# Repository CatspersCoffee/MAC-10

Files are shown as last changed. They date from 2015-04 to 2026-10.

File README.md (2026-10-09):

# MAC-10

An FPGA-based engine ignition controller (CDI), designed and built 2015–2017.

A Xilinx Spartan-6 runs a Z80 soft-core system (based on [socZ80](http://sowerbutts.com/socz80/)) with custom timer and capture peripherals. These measure engine position from a variable-reluctance pickup and fire a capacitor-discharge ignition stage on a stacked "top board".

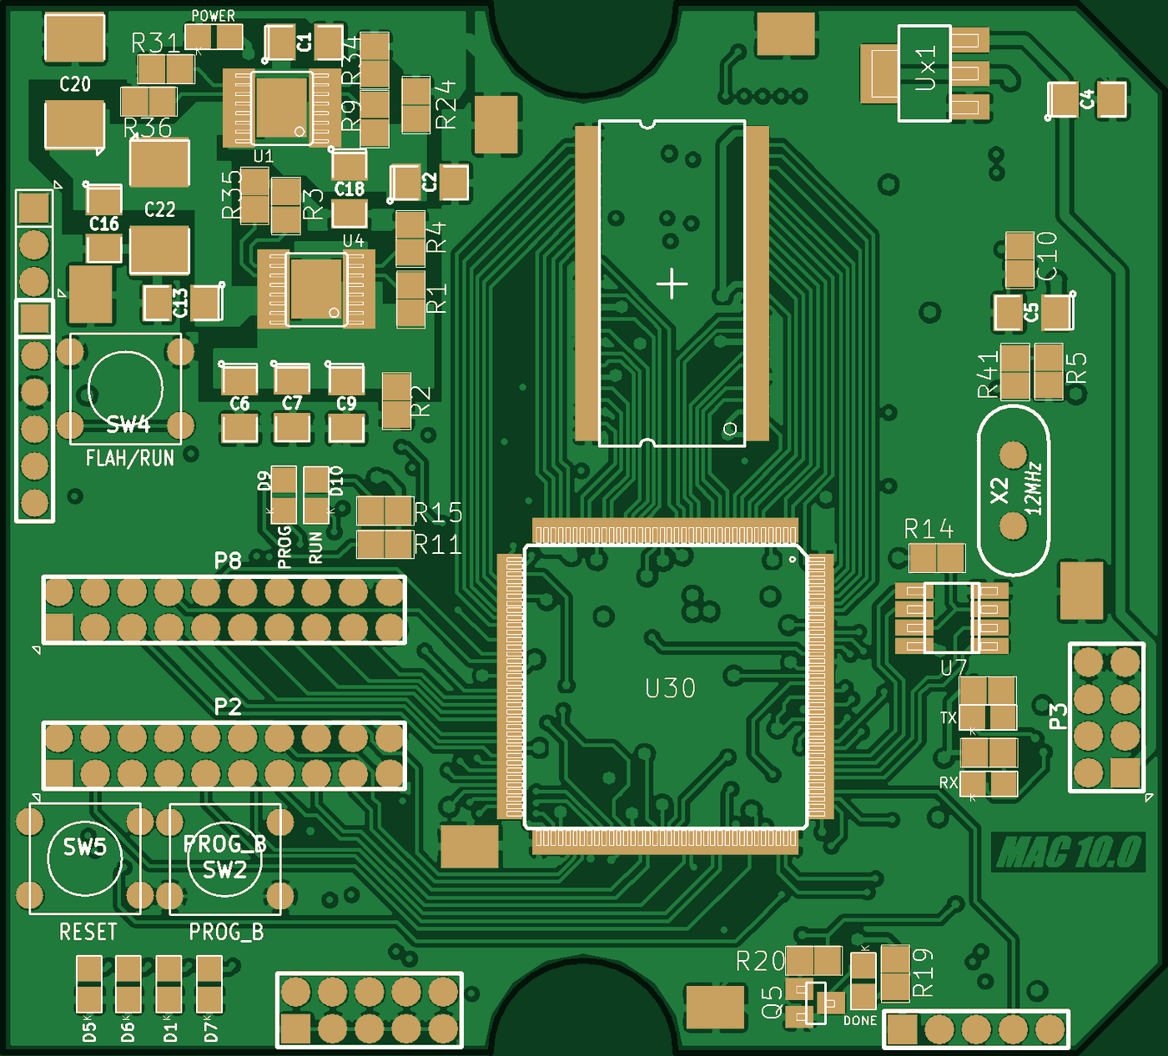
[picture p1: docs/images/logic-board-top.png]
MAC-10 logic board, top side (rendered from the fabrication gerbers)


> [!WARNING]
> The CDI board generates **several hundred volts DC** and drives an ignition coil. That can injure or kill. Do not build or power it unless you know how to work safely with high voltage.

## Boards

### Logic board: `hardware/logic-board/` (MAC10 REV 2.0)

| | |
|---|---|
| FPGA | Xilinx Spartan-6 **XC6SLX9-2TQG144** |
| Memory | Micron 256 Mb SDR SDRAM (16-bit), 2 × M25P80 SPI flash, XCF02S configuration PROM |
| Host link | FT232R USB-UART |
| Housekeeping | PIC18F2520 (programming / mode control), LT3081 regulators |
| Expansion | Two 20-pin headers (P8, P2) to the CDI board |

<p>
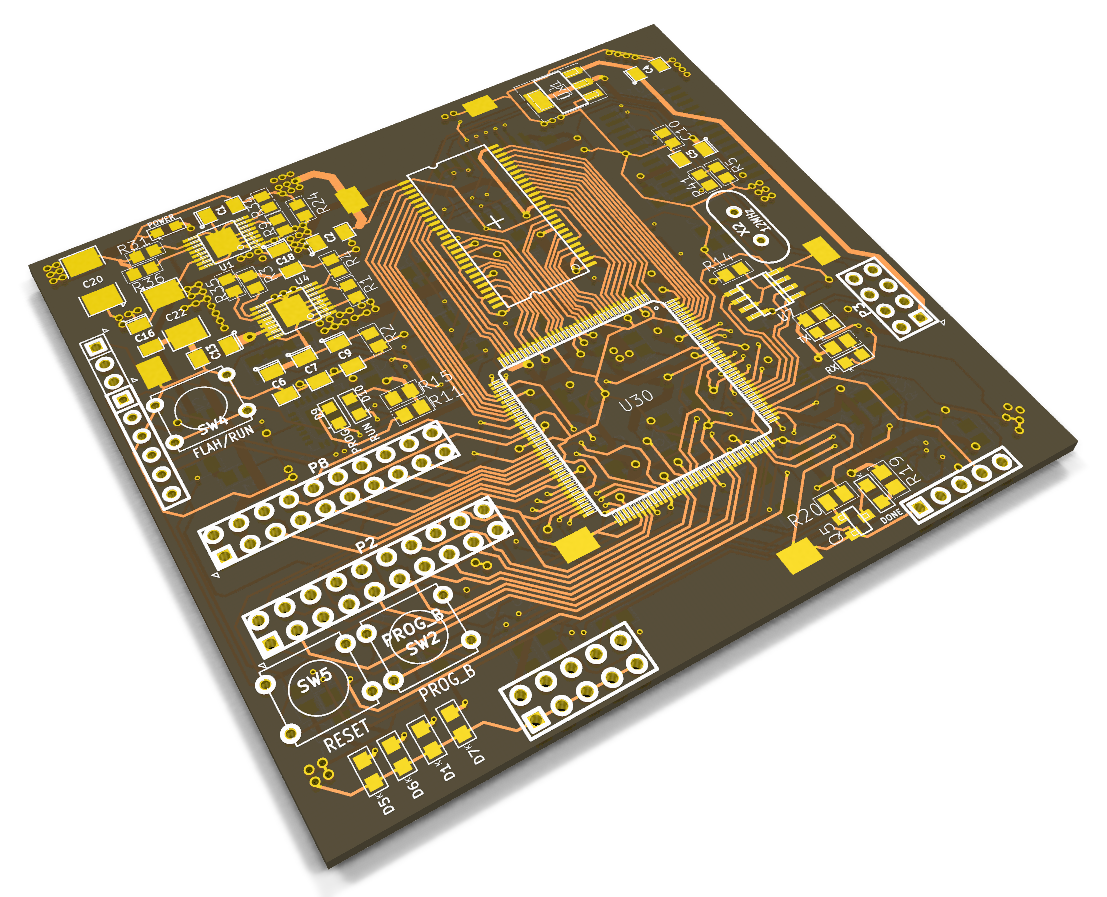
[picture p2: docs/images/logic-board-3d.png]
Logic board, 3D render

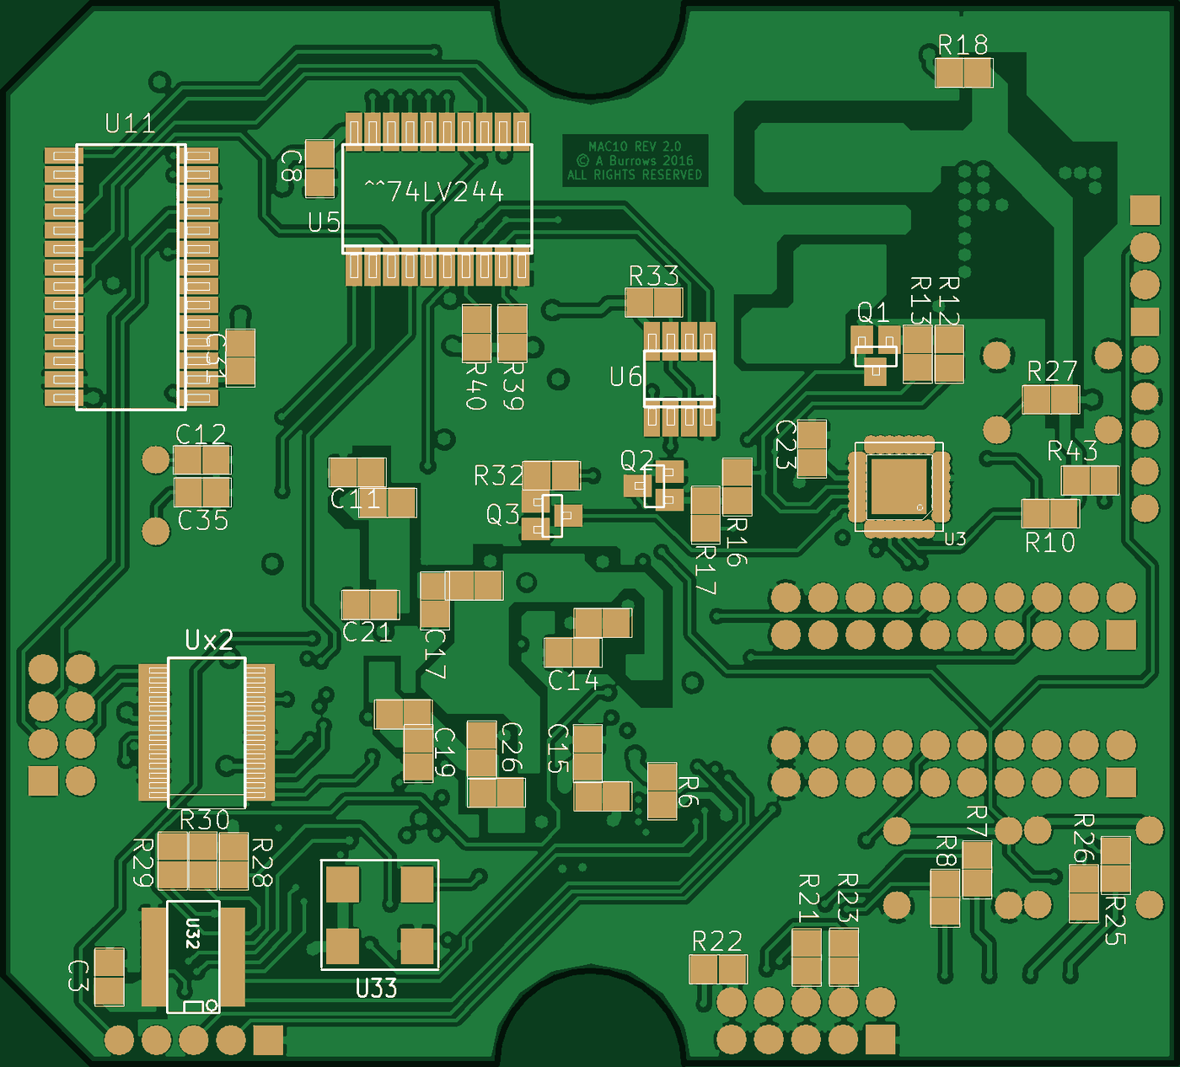
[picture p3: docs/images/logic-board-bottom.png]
Logic board, bottom side gerbers (mirrored)

</p>

### CDI board: `hardware/cdi-board/` (MAC10 TopB)

The top board stacks on the logic board through P8 (and P2 on the last revision). P8 pin 11 carries the ignition trigger from FPGA pin 59.

| | |
|---|---|
| HV supply | TL494 PWM, TC4427 driver and MOSFET push-pull into an ET029 transformer (rev 4). Earlier revisions used a MAX1771 boost converter and a BT151 SCR. |
| Crank sensing | MAX9926 variable-reluctance sensor interface |
| Temperature | MAX31855 K-type thermocouple converter |
| Inputs | MAX6816 switch debouncers, 74LVC245 level buffering |

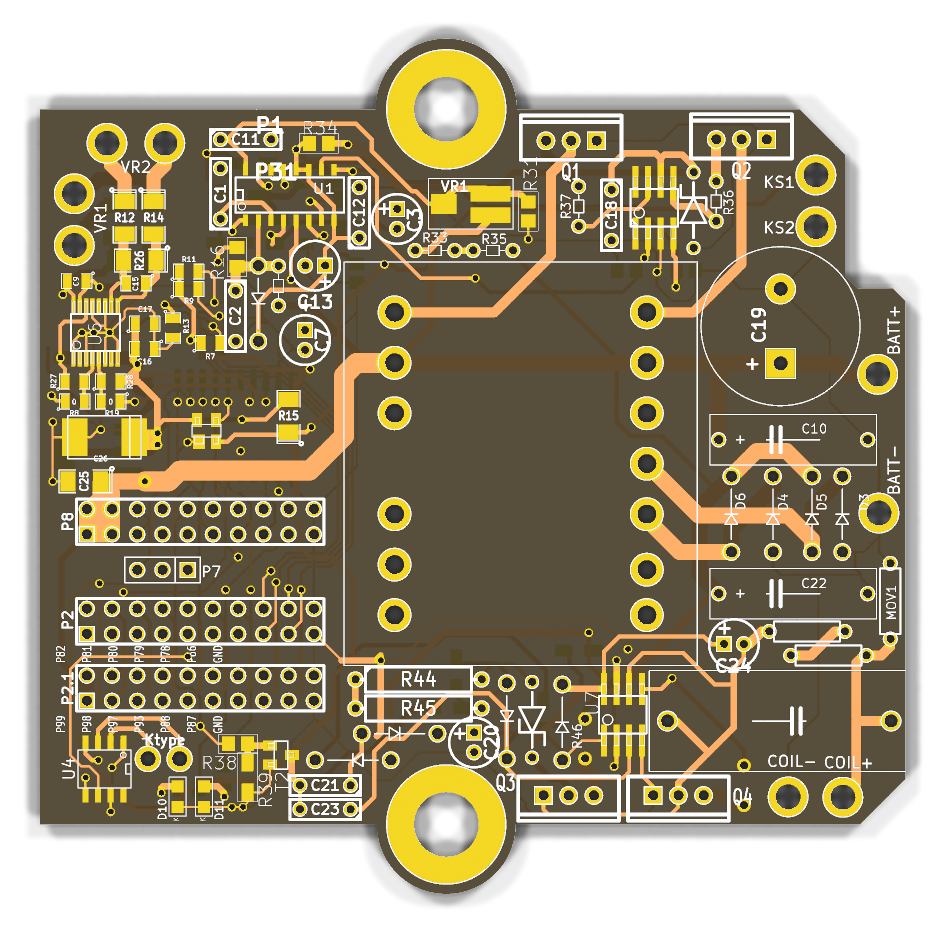
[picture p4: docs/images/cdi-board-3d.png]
CDI board, 3D render


### Gateware: `gateware/`

An ISE 14.7 project (`gateware/fpga/socz80.xise`, top level `top_level.vhd`, pinout `papilio_pro.ucf`) built on socZ80:

- **T80** Z80 CPU core, MMU, Mike Field's SDRAM controller, UARTs, SPI flash master (upstream socZ80)
- **Ignition timing peripherals** (MAC-10 additions):
  - `timerD2`: capture timer on I/O ports `0x50`–`0x57`
  - `timer3`: on `0x40`–`0x47`
  - `oneshot`: drives the CDI trigger output
- **`INTERRUPT_1`** interrupt controller, plus extra GPIO ports at `0x39`/`0x3A`
- **`hex_to_vhdl/`**: a small C tool that converts the Z80 monitor's Intel HEX into `MonZ80.vhd`, the boot ROM image

The last built bitstream is `gateware/fpga/work/top_level.bit`. The SPI PROM images are in `gateware/programming_files/`.

## Opening the files

- **KiCad:** the design files are in the 2013 KiCad format (`eeschema (2013-07-07 BZR 4022)-stable`).
  - **Boards** (`.brd`) open directly in current KiCad (checked with 10.0).
  - **Schematics** (`.sch`) need KiCad's legacy import: open the project in the KiCad GUI and accept the *Remap Symbols* step. The symbols come from each project's `*-cache.lib`, which is committed. The original custom libraries are not needed.
  - Gerbers and drill files are in each board's `GERBERS/`/`gerbers/` folder.
- **Xilinx ISE 14.7:** open `gateware/fpga/socz80.xise`. Build outputs are not committed; rebuild to regenerate them.

## History

This repository was assembled in 2026 from the original project folders. Each commit is one dated backup snapshot from the time, replayed in order. Commit dates are the real file dates, and each commit body names the original backup folder.

- `hardware/cdi-board/` passes through several design generations: TopV1, then the MAC-10.0 Test Board, then TopB 2/2E/3 (MAX1771 boost + SCR), then TopB 4 (TL494 push-pull redesign). The silkscreen REV labels don't follow the folder numbering. Each commit message gives both.
- Build outputs, editor backups, compiled executables and third-party datasheets were left out of every snapshot.

## License

- **Gateware, Z80 software and tools** (`gateware/`): [GPL-3.0-or-later](LICENSES/GPL-3.0-or-later.txt). This is required by socZ80. Upstream files keep their own headers and licenses (T80 and SSRAM are BSD-style).
- **Hardware** (`hardware/`): [CERN-OHL-S-2.0](LICENSES/CERN-OHL-S-2.0.txt).
- **Docs and images** (`docs/`): CC-BY-4.0.

The board silkscreens read "© A Burrows 2016 ALL RIGHTS RESERVED". This repository leaves the artwork exactly as it was fabricated. The notice predates this open release, and the hardware is licensed under CERN-OHL-S-2.0 as stated above.

Copyright © 2013–2017 Antony Burrows.

## Credits

- [socZ80](http://sowerbutts.com/socz80/) by William R. Sowerbutts (GPLv3): the SoC, monitor, CP/M and MP/M ports and tools this design builds on
- T80 Z80 core by Daniel Wallner
- SDRAM controller by Mike Field

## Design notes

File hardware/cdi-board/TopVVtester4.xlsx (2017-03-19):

1nF | 1 | C7
1000pF | 2 | C9 C15
4.7nF | 1 | C23
0.1uF | 1 | C17
100nF | 3 | C1 C2 C11
100nF X2 | 2 | C10 C22
120nF | 1 | C21
0.47uF 275VAC | 2 | C4 C5
1uF MMC | 2 | C12 C18
10uF | 1 | C16
100uF 16V | 2 | C20 C24
4700uF 16V LOW ESR | 1 | C19
10 uF | 5 | C3 C6 C8 C13 C14
1N4004 | 1 | D1
UF4007 | 5 | D3 D4 D5 D6 D13
1N4148 | 3 | D7 D8 D9
LED3 | 1 | D10
LED2 | 1 | D11
16V 1W | 1 | D2
75V 1W | 1 | D12
VARISTOR | 1 | MOV1
CONN_1 | 12 | P1 P3 P4 P5 P6 P9 P20 P21 P28 P29 P30 P31
CONN_10X2 | 3 | P2 P2.1 P8
CONN_3 | 1 | P7
STP60NF06 | 2 | Q1 Q2
FDP10N60 | 2 | Q3 Q4
0 | 2 | R8 R19
10 | 3 | R34 R36 R37
22 | 2 | R46 R47
300 | 1 | R11
330 | 2 | R22 R23
500 | 1 | R13
1K | 1 | R15
4.53k | 1 | R7
4K7 | 2 | R1 R20
5k | 2 | R25 R26
8K2 | 1 | R29
10K | 6 | R16 R24 R30 R31 R32 R38
10k | 4 | R10 R12 R14 R21
10k | 2 | R27 R28
13K | 1 | R40
33K | 3 | R41 R44 R45
47K | 2 | R3 R4
56K | 1 | R39
100K | 1 | R9
180K | 2 | R42 R43
270K | 2 | R33 R35
1M | 3 | R2 R17 R18
1M 0.25W | 2 | R5 R6
TRANSF_ET029 | 1 | T1
^^NPN-SOT23 | 1 | T2
TL494 | 1 | U1
OMEGA_PCC-SMP_K-TYPE | 1 | U2
TC4427 | 1 | U3
MAX31855 | 1 | U4
LT3081 | 1 | U5
L6571 | 1 | U7
MAX9926/9927 | 1 | U6
HV SEL | 1 | U8
74LVC245 | 1 | U10
100K | 1 | VR1

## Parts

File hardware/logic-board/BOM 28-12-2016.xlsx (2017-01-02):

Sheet: Sheet1
Field Value | Digikey Part # | Description | QTY
D3 D6 D7 D8 D9 | 1N4004DICT-ND | 1N4004 | 5 |  | HAVE via China
D1 D2 D4 | 1N5408RLGOSCT-ND | 1N5408 | 3 |  | HAVE via China
SF35 | SF35-TPMSCT-ND | SF35-TP | 1
L1 | ASPI-1306T-101M-TCT-ND | ASPI-1306T-101M-T | 1
L1_1 | 445-3599-1-ND |  | 1 |  | alternative sheilded inductor
L1_2 | 445-3852-1-ND |  | 1 |  | alternative sheilded inductor
R11 | 311-300ARCT-ND | RES SMD 300 OHM 5% 1/8W 0805 | 5
R13 | 311-510ARCT-ND | RES SMD 510 OHM 5% 1/8W 0805 | 5
R4 | 1.00KXBK-ND | RES 1K OHM 1/4W 1% AXIAL | 5 |  | HAVE via China
R15 | RNCP0805FTD1K00CT-ND | RES SMD 1K OHM 1% 1/4W 0805 | 5 | SMD0805
R2 | CF14JT4K70CT-ND | RES 4.7K OHM 1/4W 5% CARBON FILM | 5
R25 R26 | 541-5.1KUADKR-ND | RES SMD 5.1K OHM 5% 1/2W 1206 | 4 | SMD1206
R18 R20 R27 R28 | RHM10.0KCCT-ND | RES SMD 10K OHM 1% 1/8W 0805 | 10 | SMD0805
R10 R12 R14 R21 | RNCP1206FTD10K0CT-ND | RES SMD 10K OHM 1% 1/2W 1206 | 10 | SMD1206
R9 | 311-100KCRCT-ND | RES SMD 100K OHM 1% 1/8W 0805 | 5 | SMD0805
R5 R6 | RNF14FTD1M00CT-ND | RES 1M OHM 1/4W 1% AXIAL | 10 |  | HAVE via China
R17 | PT1.5MXCT-ND | RES SMD 1.5M OHM 5% 1W 2512 | 2 | SMD2512
R1 | CF14JT330RCT-ND | RES 330 OHM 1/4W 5% CARBON FILM | 5
R3 | S51CACT-ND | RES 51 OHM 1/4W 1% AXIAL | 5 |  | HAVE via China
R16 | P50MCT-ND | RES SMD 0.05 OHM 1% 1W 2512 | 2 | SMD2512
T1 | IRF644PBF-ND | MOSFET N-CH 250V 14A TO-220AB | 3
TH1 | KC002N-ND | THERMISTOR NTC 500 OHM @ 25C | 2
U3 | MAX1771ESA+-ND | IC REG CTRLR BST PWM 8-SOIC | 2
U7 | MAX6816EUS+TCT-ND | IC DEBOUNCER SWITCH SGL SOT143-4 | 2
U6 | MAX9926UAEE+TCT-ND | IC SENSOR INTERFACE VARI 16-QSOP | 2
VR1 | 3214W-502ECT-ND | TRIMMER 5K OHM 0.25W SMD | 2
C13 | PCF1412CT-ND | CAP FILM 0.1UF 5% 250VDC 2420 | 3 | SMD2420
C1 C3 C10 C11 | 490-1726-1-ND | CAP CER 0.1UF 25V Y5V 0805 | 10 | SMD0805
C7 | 478-1762-1-ND | CAP TANT 10UF 25V 10% 2312 | 3 | SMD2312
C18 | 478-1746-1-ND | CAP TANT 100UF 20V 10% 2917 | 2 | SMD2917
C6 | 399-3684-1-ND | CAP TANT 10UF 10V 10% 1206 | 2 | SMD1206
C8 | 478-8234-1-ND | CAP TANT 1UF 16V 20% 1206 | 2 | SMD1206
C12 | 478-4973-1-ND | CAP TANT 10UF 35V 20% 2312 | 1 | SMD2312 | changed package | OR change to 2917 (7343 metric)
C14 | 478-1710-1-ND | CAP TANT 2.2UF 35V 10% 2312 | 1 | SMD2312 | changed package
C2 | 445-8351-ND | CAP CER 10UF 25V X7R RADIAL | 1
C9 C15 | 445-1337-1-ND | CAP CER 1000PF 100V X7R 0805 | 10 | SMD0805
C4 C5 | P14596-ND | CAP FILM 1UF 5% 250VDC RADIAL | 4 |  | Lead Spacing 0.591" (15.00mm)
U30 | 122-1748-ND | XC6SLX9-3TQG144I | 1
U32 | 122-1288-5-ND | XCF04SVOG20C | 1
U33 | CTX277LVCT-ND | OSC XO 32.000MHZ HCMOS TTL SMD | 2
Ux2 | 768-1007-1-ND | IC USB FS SERIAL UART 28-SSOP | 1
X2 | 631-1105-ND | 12MHz ±30ppm Crystal 18pF HC49/US | 1
U6 U7 | M25P20-VMN6TPBCT-ND | IC FLASH 2MBIT 75MHZ 8SO | 2
U6 U7 | 1265-1133-1-ND | IC FLASH 8MBIT 75MHZ 8SO | 2
R34 | 311-66.5KCRCT-ND | RES SMD 66.5K OHM 1% 1/8W 0805 | 5 | SMD0805
R4 | P24.3KCCT-ND | RES SMD 24.3K OHM 1% 1/8W 0805 | 5 | SMD0805
R10 R27 R39 R40 | RHM10.0KCCT-ND | RES SMD 10K OHM 1% 1/8W 0805 | 10 | SMD0805
R6 R28 R30 R43 | 311-4.70KCRCT-ND | RES SMD 4.7K OHM 1% 1/8W 0805 | 10 | SMD0805
R1 R9 | 311-4.53KCRCT-ND | RES SMD 4.53K OHM 1% 1/8W 0805 | 5 | SMD0805
R14 R33 R35 R36 | RNCP0805FTD1K00CT-ND | RES SMD 1K OHM 1% 1/4W 0805 | 10 | SMD0805
R3 R31 | 311-510ARCT-ND | RES SMD 510 OHM 5% 1/8W 0805 | 5 | SMD0805
R21 R22 R23 | 311-100CRCT-ND | RES SMD 100 OHM 1% 1/8W 0805 | 5 | SMD0805
C5 | 399-8273-1-ND | CAP TANT 0.22UF 35V 10% 1206 | 2 | SMD1206
C20 C22 | 478-4973-1-ND | CAP TANT 10UF 35V 20% 2312 | 1 | SMD2312
X1 | 631-1122-1-ND | OSCILLATOR XO 1.000MHZ HCMOS SMD | 1 | SMD
U72 | 296-12896-5-ND | 74HC27 | 5
U19 | 296-12892-5-ND | 74HC20 | 2
U5 U71 U81 | 296-1589-5-ND | 74HC32 | 8
U15 | 296-2138-5-ND | 74HCT93 | 2
U79 | 296-1568-5-ND | 74HC05 | 3
U90 | 296-9196-5-ND | 74HC30 | 4
U1 | 296-9240-5-ND | 74HC75 | 3
U18 | 296-8257-5-ND | 74HC175 | 2
U9 U73 U74 U75 | 296-1591-5-ND | 74HC373 | 6
U56 | 296-1580-5-ND | 74HC240 | 2
U15 | 1450-1027-ND | AS6C4008-55PCN | 5
U17, U40 | 296-4290-5-ND | 74AC04 | 2
U8 | 296-4301-5-ND | 74AC14 | 1
U10, U11, U12, U13 | 296-4315-5-ND | 74AC245 | 4
U2, U3, U4, U5, U6 | 296-26376-5-ND | 74AC373 | 5
U9 | 296-1566-5-ND | 74HC04 | 1
U26, U41 |  | 74LS07 | 2
U14 | 296-8214-5-ND | 74HC10 | 1
U23, U28, U29, U30, U31 | 296-1589-5-ND | 74HC32 | 5
U27 | 296-8230-5-ND | 74HC139 | 1
U1 | 296-8248-5-ND | 74HC164 | 1
U20 | 296-8357-5-ND | 74HC682 | 1

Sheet: TopB V2
TopB V2
1000pF | 2 | C9 C15 | SMD0805
0.1uF | 1 | C19 | decouple 0805
0.1uF | 1 | C17 | decouple 0805
100nF | 4 | C1 C10 C11 | SMD0805
100nF |  | C3 | through hole | have via china
100nF 250V | 1 | C13 | SMD2420
0.47uF 275VAC | 2 | C4 C5
10uF 25V | 1 | C2
10uF | 1 | C16 | decouple 0805
10 uF tant | 1 | C6 | SMD1206
 | 1 | C8 | SMD1206
tant | 1 | C12
 | 1 | C14
 |  | C7 | SMD2312
 |  | C18 | SMD2917
1N5408 | 3 | D1 D2 D4
1N4004 | 5 | D3 D6 D7 D8 D9
SF35 | 1 | D5
LED3 | 1 | D10
LED2 | 1 | D11
INDUCTOR | 1 | L1
CONN_1 | 13 | P1 P2 P20 P21 P22 P23 P24 P26 P27 P28 P29 P30 P31
CONN_10X2 | 1 | P8
CONN_3 | 1 | P7
0 | 2 | R8 R19
300 | 1 | R11
330 | 2 | R22 R23
500 | 1 | R13
1K 0.25W | 1 | R4
1K | 1 | R15
4.53k | 1 | R7 | Take out
4K7 0.25W | 1 | R2
5k | 2 | R25 R26 | SMD1206
10K | 2 | R18 | SMD0805
10K | 2 | R20 | SMD0805
10k | 4 | R10 R12 R14 R21 | SMD1206
10k | 2 | R27 R28 | SMD0805
100K | 1 | R9 | SMD0805
1M 0.25W | 2 | R5 R6
1M5 | 1 | R17 | SMD2512
330 0.25W | 1 | R1
51ohm 0.25W | 1 | R3
RSENSE 0.05ohm | 1 | R16 | SMD2512
BT151 | 1 | SCR1
IRF644 | 1 | T1
NTC | 1 | TH1
4N25 | 1 | U1
OMEGA_PCC-SMP_K-TYPE | 1 | U2
MAX1771 | 1 | U3
MAX31855 | 1 | U4
LT3081 | 1 | U5
MAX6816 | 1 | U7
MAX9926/9927 | 1 | U6
HV SEL | 1 | U8
74LVC245 | 1 | U10
5K | 1 | VR1

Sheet: MAC10v2
0.1 uF | 12 | C3 C8 C10 C11 C14 C15 C17 C19 C21 C23 C26 C31 | decouple caps 0805
10 uF | 9 | C1 C2 C4 C6 C7 C9 C13 C16 C18 | SMD1206 | http://www.ebay.com/itm/100-PCS-A-1uF-35V-1206-3216-SMD-Tantalum-Capacitor-/321448011348
10uF | 2 | C20 C22 | SMD2312 | changed package from 1812 to 2312
22 uF | 1 | C5
15 pF | 2 | C12 C35 | use instock ones from RS
LED1 | 1 | D1
POWER | 1 | D2
LED | 3 | D3 Dx1 Dx2
LED3 | 1 | D5
LED2 | 1 | D6
LED0 | 1 | D7
RUN | 1 | D9
PROG | 1 | D10
FPGA PINS | 1 | P1
CONN_10X2 | 2 | P2 P8
PIC_ISP | 1 | P5
XILINX CABLE | 1 | P20
USB_Header | 1 | P3
DC IN | 1 | P15 | take out
^^NPN-BC817-SOT323 | 1 | Q5
^^NPN-SOT23 | 3 | Q1 Q2 Q3
0 | 8 | R5 R20 R7000 R7001 R7002 R7003 R7004 R7005 | use 0ohm ones in stock from china
100 | 3 | R21 R22 R23
300 | 2 | R2 R24 | get from china | http://www.ebay.com/itm/200pcs-300-ohm-300R-1-0805-2012-1-8W-SMD-Chip-Resistor-2mm-1-2mm-/331716171044
330 | 12 | R7 R8 R11 R15 R18 R19 R25 R26 R29 R41 Rx1 Rx2 | get from china | http://www.ebay.com/itm/5000PCS-0805-Chip-Resistors-330-ohm-330R-1-SMD-Resistors-1-8W-Chip-Resistor-/251924323249
470 | 5 | R12 R13 R16 R17 R32 | use 100ohm ones in stock from china
500 | 2 | R3 R31
1K | 4 | R14 R33 R35 R36
4.53k | 2 | R1 R9
4K7 | 4 | R6 R28 R30 R43
10k | 2 | R10 R27
10K | 2 | R39 R40
24.3K | 1 | R4
66.5K | 1 | R34
PROG_B | 1 | SW2
FLASH/RUN | 1 | SW4
SOFT_RESET | 1 | SW5
LT3081 | 2 | U1 U4
MT48LC64M4A2 | 1 | U2 | Have instock from Ebay
M25P80 | 2 | U6 U7
CH341A | 1 | U11
XC6SLX9-TQ144 | 1 | U30
XCF02S | 1 | U32
FPGA_CLK_0 | 1 | U33
PIC18F2520-28QFN | 1 | U3 | Have instock from Ebay
^^74LV244 | 1 | U5 | Have instock from RS
FT232R | 1 | Ux2
^^3.3VREG_SOT223 | 1 | Ux1 | Have instock from Ebay LM1117 3.3
12MHz | 1 | X2

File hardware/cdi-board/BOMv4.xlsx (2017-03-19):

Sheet: Sheet1
Field Value | Digikey Part # | Description | QTY
MOV1 | MOV-14D431K-ND | VARISTOR 430V 4.5KA DISC 14MM | 1
U1 | 296-10193-5-ND | TL494 IC REG CTRLR MULT TOP 16SOIC | 1
Q1 Q2 | 497-2779-5-ND | STP60NF06 MOSFET N-CH 60V 60A TO-220 | 2
U3 | TC4427AEOA-ND | TC4427A IC MOSFET DVR 1.5A DUAL HS 8SOIC | 1
U7 | 497-3367-1-ND | L6571 IC DRVR HALF-BRG W/OSC HV 8-SOIC | 1
Q3 Q4 | FDP10N60NZ-ND | FDP10N60NZ MOSFET N-CH 600V 10A TO-220 | 2
D7 D8 D9 | 1N4148FS-ND | 1N4148 | 10
D12 | 1N4761A CT-ND | DIODE ZENER 75V 1W DO41 | 1
D2 | 1N4745AFSCT-ND | DIODE ZENER 16V 1W DO41 | 1
D1 | 1N4004DICT-ND | 1N4004 | 1
D3 D4 D5 D6 D13 | UF4007CT-ND | UF4007 | 5
T1 | 495-5453-ND | YOKE ETD 29 X 16 X 10 | 2
T1 | 495-5448-ND | FERRITE CORE ETD N87 1PC | 2
T1 | 495-5452-ND | BOBBIN COIL FORMER ETD 29X16X10 | 1
VR1 | 3214X-1-104ECT-ND | TRIMMER 100K OHM 0.25W SMD | 1
U10 | 568-2300-1-ND | 74LVC245 IC TRANSCVR TRI-ST 8BIT 20SOIC | 1
T2 | BC817-25-TPMSCT-ND | TRANS NPN 45V 0.8A SOT-23 | 1
C7 | 399-5434-ND | 1nF CAP FILM 1000PF 10% 63VDC RADIAL | 1
C23 | BC2686CT-ND | 4.7nF CAP CER 0.047UF 50V X7R RADIAL | 1
C1 C2 C11 | 338-3263-ND | 100nF 0.10µF ±10% Film Capacitor 63V 100V Polyester, Metallized Radial | 3
C10 C22 | 1572-1006-ND | 100nF X2 CAP FILM 0.1UF 10% 310VAC RADIAL | 2
C21 | 399-3509-ND | 120nF 0.12µF ±10% 500V Ceramic Capacitor X7R | 1
C4 C5 |  | 0.47uF 275VAC | 2
C12 C18 | 445-8517-ND | 1uF MMC CER 1UF 50V X7R RADIAL | 2
C20 C24 | 493-10975-1-ND | 100uF CAP ALUM 100UF 20% 16V RADIAL | 2
C19 | P10263-ND | 4700µF 16V Aluminum Capacitors Radial, | 1
C3 C6 C8 C13 C14 | 493-12763-1-ND | 10 uF 10µF 16V Aluminum Capacitors Radial | 5
R34 R36 R37 | RNCP0805FTD10R0CT-ND | 10 Ohm ±1% 0.25W, 1/4W Chip Resistor 0805 | 3
R36 R37 | S10CATR-ND | 10 Ohm ±1% 0.25W, 1/4W Through Hole Resistor Axial | 2
R46 R47 | RPC0805JT22R0CT-ND | RES SMD 22 OHM 5% 1/4W 0805 | 2
R41 | P21190CT-ND | RES SMD 33K OHM 0.5% 1/4W 0805 | 1
R44 R45 | PPC33KW-1CT-ND | RES 33K OHM 1W 5% AXIAL | 2
R42 R43 | P21274CT-ND | RES SMD 180K OHM 0.5% 1/4W 0805 | 2
R16 R24 R30 R31 R32 R38 | RNCP0805FTD10K0CT-ND | RES SMD 10K OHM 1% 1/4W 0805 | 6
R39 | P21218CT-ND | RES SMD 56K OHM 0.5% 1/4W 0805 | 1
R29 | S8.2KCACT-ND | 8.2k Ohm ±1% 0.25W, 1/4W Through Hole Resistor Axial | 1
R3 R4 | ERJ-PB6D4702V | RES SMD 47K OHM 0.5% 1/4W 0805 | 2
R2 R17 R18 | RPC0805JT1M00CT-ND | 1M Ohm ±5% 0.25W, 1/4W Chip Resistor 0805 | 3
R5 R6 | S680KCACT-ND | RES 680K OHM 1/4W 1% AXIAL | 2
R1 R20 | P21095CT-ND | RES SMD 4.7K OHM 0.5% 1/4W 0805 | 2
R46 R47 | S22CACT-ND | RES 22 OHM 1/4W 1% AXIAL | 2
R40 | P21145CT-ND | RES SMD 13K OHM 0.5% 1/4W 0805 | 1
R33 R35 | S270KCACT-ND | RES 270K OHM 1/4W 1% AXIAL | 2
D3 D6 D7 D8 D9 | 1N4004DICT-ND | 1N4004 | 5 |  | HAVE via China
D1 D2 D4 | 1N5408RLGOSCT-ND | 1N5408 | 3 |  | HAVE via China
SF35 | SF35-TPMSCT-ND | SF35-TP | 1
L1 | ASPI-1306T-101M-TCT-ND | ASPI-1306T-101M-T | 1
L1_1 | 445-3599-1-ND |  | 1 |  | alternative sheilded inductor
L1_2 | 445-3852-1-ND |  | 1 |  | alternative sheilded inductor
R11 | 311-300ARCT-ND | RES SMD 300 OHM 5% 1/8W 0805 | 5
R13 | 311-510ARCT-ND | RES SMD 510 OHM 5% 1/8W 0805 | 5
R4 | 1.00KXBK-ND | RES 1K OHM 1/4W 1% AXIAL | 5 |  | HAVE via China
R15 | RNCP0805FTD1K00CT-ND | RES SMD 1K OHM 1% 1/4W 0805 | 5 | SMD0805
R2 | CF14JT4K70CT-ND | RES 4.7K OHM 1/4W 5% CARBON FILM | 5
R25 R26 | 541-5.1KUADKR-ND | RES SMD 5.1K OHM 5% 1/2W 1206 | 4 | SMD1206
R18 R20 R27 R28 | RHM10.0KCCT-ND | RES SMD 10K OHM 1% 1/8W 0805 | 10 | SMD0805
R10 R12 R14 R21 | RNCP1206FTD10K0CT-ND | RES SMD 10K OHM 1% 1/2W 1206 | 10 | SMD1206
R9 | 311-100KCRCT-ND | RES SMD 100K OHM 1% 1/8W 0805 | 5 | SMD0805
R5 R6 | RNF14FTD1M00CT-ND | RES 1M OHM 1/4W 1% AXIAL | 10 |  | HAVE via China
R17 | PT1.5MXCT-ND | RES SMD 1.5M OHM 5% 1W 2512 | 2 | SMD2512
R1 | CF14JT330RCT-ND | RES 330 OHM 1/4W 5% CARBON FILM | 5
R3 | S51CACT-ND | RES 51 OHM 1/4W 1% AXIAL | 5 |  | HAVE via China
R16 | P50MCT-ND | RES SMD 0.05 OHM 1% 1W 2512 | 2 | SMD2512
T1 | IRF644PBF-ND | MOSFET N-CH 250V 14A TO-220AB | 3
TH1 | KC002N-ND | THERMISTOR NTC 500 OHM @ 25C | 2
U3 | MAX1771ESA+-ND | IC REG CTRLR BST PWM 8-SOIC | 2
U7 | MAX6816EUS+TCT-ND | IC DEBOUNCER SWITCH SGL SOT143-4 | 2
U6 | MAX9926UAEE+TCT-ND | IC SENSOR INTERFACE VARI 16-QSOP | 2
VR1 | 3214W-502ECT-ND | TRIMMER 5K OHM 0.25W SMD | 2
C13 | PCF1412CT-ND | CAP FILM 0.1UF 5% 250VDC 2420 | 3 | SMD2420
C1 C3 C10 C11 | 490-1726-1-ND | CAP CER 0.1UF 25V Y5V 0805 | 10 | SMD0805
C7 | 478-1762-1-ND | CAP TANT 10UF 25V 10% 2312 | 3 | SMD2312
C18 | 478-1746-1-ND | CAP TANT 100UF 20V 10% 2917 | 2 | SMD2917
C6 | 399-3684-1-ND | CAP TANT 10UF 10V 10% 1206 | 2 | SMD1206
C8 | 478-8234-1-ND | CAP TANT 1UF 16V 20% 1206 | 2 | SMD1206
C12 | 478-4973-1-ND | CAP TANT 10UF 35V 20% 2312 | 1 | SMD2312 | changed package | OR change to 2917 (7343 metric)
C14 | 478-1710-1-ND | CAP TANT 2.2UF 35V 10% 2312 | 1 | SMD2312 | changed package
C2 | 445-8351-ND | CAP CER 10UF 25V X7R RADIAL | 1
C9 C15 | 445-1337-1-ND | CAP CER 1000PF 100V X7R 0805 | 10 | SMD0805
C4 C5 | P14596-ND | CAP FILM 1UF 5% 250VDC RADIAL | 4 |  | Lead Spacing 0.591" (15.00mm)
U30 | 122-1748-ND | XC6SLX9-3TQG144I | 1
U32 | 122-1288-5-ND | XCF04SVOG20C | 1
U33 | CTX277LVCT-ND | OSC XO 32.000MHZ HCMOS TTL SMD | 2
Ux2 | 768-1007-1-ND | IC USB FS SERIAL UART 28-SSOP | 1
X2 | 887-1013-ND | 12MHz ±30ppm Crystal 18pF HC49/US | 1
U6 U7 | M25P20-VMN6TPBCT-ND | IC FLASH 2MBIT 75MHZ 8SO | 2
U6 U7 | M25P80-VMN6TPCT-ND | IC FLASH 8MBIT 75MHZ 8SO | 2
R34 | 311-66.5KCRCT-ND | RES SMD 66.5K OHM 1% 1/8W 0805 | 5 | SMD0805
R4 | P24.3KCCT-ND | RES SMD 24.3K OHM 1% 1/8W 0805 | 5 | SMD0805
R10 R27 R39 R40 | RHM10.0KCCT-ND | RES SMD 10K OHM 1% 1/8W 0805 | 10 | SMD0805
R6 R28 R30 R43 | 311-4.70KCRCT-ND | RES SMD 4.7K OHM 1% 1/8W 0805 | 10 | SMD0805
R1 R9 | 311-4.53KCRCT-ND | RES SMD 4.53K OHM 1% 1/8W 0805 | 5 | SMD0805
R14 R33 R35 R36 | RNCP0805FTD1K00CT-ND | RES SMD 1K OHM 1% 1/4W 0805 | 10 | SMD0805
R3 R31 | 311-510ARCT-ND | RES SMD 510 OHM 5% 1/8W 0805 | 5 | SMD0805
R21 R22 R23 | 311-100CRCT-ND | RES SMD 100 OHM 1% 1/8W 0805 | 5 | SMD0805
C5 | 399-8273-1-ND | CAP TANT 0.22UF 35V 10% 1206 | 2 | SMD1206
C20 C22 | 478-4973-1-ND | CAP TANT 10UF 35V 20% 2312 | 1 | SMD2312
X1 | 631-1122-1-ND | OSCILLATOR XO 1.000MHZ HCMOS SMD | 1 | SMD

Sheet: TopB V2
TopB V2
1000pF | 2 | C9 C15 | SMD0805
0.1uF | 1 | C19 | decouple 0805
0.1uF | 1 | C17 | decouple 0805
100nF | 4 | C1 C10 C11 | SMD0805
100nF |  | C3 | through hole | have via china
100nF 250V | 1 | C13 | SMD2420
0.47uF 275VAC | 2 | C4 C5
10uF 25V | 1 | C2
10uF | 1 | C16 | decouple 0805
10 uF tant | 1 | C6 | SMD1206
 | 1 | C8 | SMD1206
tant | 1 | C12
 | 1 | C14
 |  | C7 | SMD2312
 |  | C18 | SMD2917
1N5408 | 3 | D1 D2 D4
1N4004 | 5 | D3 D6 D7 D8 D9
SF35 | 1 | D5
LED3 | 1 | D10
LED2 | 1 | D11
INDUCTOR | 1 | L1
CONN_1 | 13 | P1 P2 P20 P21 P22 P23 P24 P26 P27 P28 P29 P30 P31
CONN_10X2 | 1 | P8
CONN_3 | 1 | P7
0 | 2 | R8 R19
300 | 1 | R11
330 | 2 | R22 R23
500 | 1 | R13
1K 0.25W | 1 | R4
1K | 1 | R15
4.53k | 1 | R7 | Take out
4K7 0.25W | 1 | R2
5k | 2 | R25 R26 | SMD1206
10K | 2 | R18 | SMD0805
10K | 2 | R20 | SMD0805
10k | 4 | R10 R12 R14 R21 | SMD1206
10k | 2 | R27 R28 | SMD0805
100K | 1 | R9 | SMD0805
1M 0.25W | 2 | R5 R6
1M5 | 1 | R17 | SMD2512
330 0.25W | 1 | R1
51ohm 0.25W | 1 | R3
RSENSE 0.05ohm | 1 | R16 | SMD2512
BT151 | 1 | SCR1
IRF644 | 1 | T1
NTC | 1 | TH1
4N25 | 1 | U1
OMEGA_PCC-SMP_K-TYPE | 1 | U2
MAX1771 | 1 | U3
MAX31855 | 1 | U4
LT3081 | 1 | U5
MAX6816 | 1 | U7
MAX9926/9927 | 1 | U6
HV SEL | 1 | U8
74LVC245 | 1 | U10
5K | 1 | VR1

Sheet: MAC10v2
0.1 uF | 12 | C3 C8 C10 C11 C14 C15 C17 C19 C21 C23 C26 C31 | decouple caps 0805
10 uF | 9 | C1 C2 C4 C6 C7 C9 C13 C16 C18 | SMD1206 | http://www.ebay.com/itm/100-PCS-A-1uF-35V-1206-3216-SMD-Tantalum-Capacitor-/321448011348
10uF | 2 | C20 C22 | SMD2312 | changed package from 1812 to 2312
22 uF | 1 | C5
15 pF | 2 | C12 C35 | use instock ones from RS
LED1 | 1 | D1
POWER | 1 | D2
LED | 3 | D3 Dx1 Dx2
LED3 | 1 | D5
LED2 | 1 | D6
LED0 | 1 | D7
RUN | 1 | D9
PROG | 1 | D10
FPGA PINS | 1 | P1
CONN_10X2 | 2 | P2 P8
PIC_ISP | 1 | P5
XILINX CABLE | 1 | P20
USB_Header | 1 | P3
DC IN | 1 | P15 | take out
^^NPN-BC817-SOT323 | 1 | Q5
^^NPN-SOT23 | 3 | Q1 Q2 Q3
0 | 8 | R5 R20 R7000 R7001 R7002 R7003 R7004 R7005 | use 0ohm ones in stock from china
100 | 3 | R21 R22 R23
300 | 2 | R2 R24 | get from china | http://www.ebay.com/itm/200pcs-300-ohm-300R-1-0805-2012-1-8W-SMD-Chip-Resistor-2mm-1-2mm-/331716171044
330 | 12 | R7 R8 R11 R15 R18 R19 R25 R26 R29 R41 Rx1 Rx2 | get from china | http://www.ebay.com/itm/5000PCS-0805-Chip-Resistors-330-ohm-330R-1-SMD-Resistors-1-8W-Chip-Resistor-/251924323249
470 | 5 | R12 R13 R16 R17 R32 | use 100ohm ones in stock from china
500 | 2 | R3 R31
1K | 4 | R14 R33 R35 R36
4.53k | 2 | R1 R9
4K7 | 4 | R6 R28 R30 R43
10k | 2 | R10 R27
10K | 2 | R39 R40
24.3K | 1 | R4
66.5K | 1 | R34
PROG_B | 1 | SW2
FLASH/RUN | 1 | SW4
SOFT_RESET | 1 | SW5
LT3081 | 2 | U1 U4
MT48LC64M4A2 | 1 | U2 | Have instock from Ebay
M25P80 | 2 | U6 U7
CH341A | 1 | U11
XC6SLX9-TQ144 | 1 | U30
XCF02S | 1 | U32
FPGA_CLK_0 | 1 | U33
PIC18F2520-28QFN | 1 | U3 | Have instock from Ebay
^^74LV244 | 1 | U5 | Have instock from RS
FT232R | 1 | Ux2
^^3.3VREG_SOT223 | 1 | Ux1 | Have instock from Ebay LM1117 3.3
12MHz | 1 | X2

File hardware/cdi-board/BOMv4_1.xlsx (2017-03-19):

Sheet: Sheet1
Field Value | Digikey Part # | Description | QTY | QTYx2
 |  |  |  | 0
MOV1 | MOV-14D431K-ND | VARISTOR 430V 4.5KA DISC 14MM | 1 | 2
U1 | 296-10193-5-ND | TL494 IC REG CTRLR MULT TOP 16SOIC | 1 | 4
Q1 Q2 | 497-2779-5-ND | STP60NF06 MOSFET N-CH 60V 60A TO-220 | 2 | 6
U3 | TC4427AEOA-ND | TC4427A IC MOSFET DVR 1.5A DUAL HS 8SOIC | 1 | 4
U7 | 497-3367-1-ND | L6571 IC DRVR HALF-BRG W/OSC HV 8-SOIC | 1 | 4
Q3 Q4 | FDP10N60NZ-ND | FDP10N60NZ MOSFET N-CH 600V 10A TO-220 | 2 | 6
D7 D8 D9 | 1N4148FS-ND | 1N4148 | 10 | 20
D12 | 1N4761A CT-ND | DIODE ZENER 75V 1W DO41 | 1 | 5
D2 | 1N4745AFSCT-ND | DIODE ZENER 16V 1W DO41 | 1 | 5
D1 | 1N4004DICT-ND | 1N4004 | 1 | 5
D3 D4 D5 D6 D13 | UF4007CT-ND | UF4007 | 5 | 10
T1 | 495-5453-ND | YOKE ETD 29 X 16 X 10 | 2 | 6
T1 | 495-5448-ND | FERRITE CORE ETD N87 1PC | 2 | 2
T1 | 495-5452-ND | BOBBIN COIL FORMER ETD 29X16X10 | 1 | 3
VR1 | 3214X-1-104ECT-ND | TRIMMER 100K OHM 0.25W SMD | 1 | 3
U10 | 568-2300-1-ND | 74LVC245 IC TRANSCVR TRI-ST 8BIT 20SOIC | 1 | 3
T2 | BC817-25-TPMSCT-ND | TRANS NPN 45V 0.8A SOT-23 | 1 | 3
C7 | 399-5434-ND | 1nF CAP FILM 1000PF 10% 63VDC RADIAL | 1 | 2
C23 | BC2686CT-ND | 4.7nF CAP CER 0.047UF 50V X7R RADIAL | 1 | 2
C1 C2 C11 | 338-3263-ND | 100nF 0.10µF ±10% Film Capacitor 63V 100V Polyester, Metallized Radial | 3 | 6
C10 C22 | 1572-1006-ND | 100nF X2 CAP FILM 0.1UF 10% 310VAC RADIAL | 2 | 4
C21 | 399-3509-ND | 120nF 0.12µF ±10% 500V Ceramic Capacitor X7R | 1 | 1
C12 C18 | 445-8517-ND | 1uF MMC CER 1UF 50V X7R RADIAL | 2 | 4
C20 C24 | 493-10975-1-ND | 100uF CAP ALUM 100UF 20% 16V RADIAL | 2 | 4
C19 | P10263-ND | 4700µF 16V Aluminum Capacitors Radial, | 1 | 3
C3 C6 C8 C13 C14 | 493-12763-1-ND | 10 uF 10µF 16V Aluminum Capacitors Radial | 5 | 10
R34 R36 R37 | RNCP0805FTD10R0CT-ND | 10 Ohm ±1% 0.25W, 1/4W Chip Resistor 0805 | 3 | 6
R36 R37 | S10CATR-ND | 10 Ohm ±1% 0.25W, 1/4W Through Hole Resistor Axial | 2 | 5
R46 R47 | 311-22.0FRCT-ND | RES SMD 22 OHM 1% 1/4W 1206 | 2 | 5
R41 | RMCF1206FT33K0CT-ND | RES SMD 33K OHM 1% 1/4W 1206 | 1 | 5
R44 R45 | RNMF14FTC33K0CT-ND | RES 33K OHM 1/4W 1% AXIAL | 2 | 4
R42 R43 | 311-180KFRCT-ND | RES SMD 180K OHM 1% 1/4W 1206 | 2 | 4
R16 R24 R30 R31 R32 R38 | RNCP0805FTD10K0CT-ND | RES SMD 10K OHM 1% 1/4W 0805 | 6 | 12
R39 | P56.0KFCT-ND | RES SMD 56K OHM 1% 1/4W 1206 | 1 | 2
R29 | S8.2KCACT-ND | 8.2k Ohm ±1% 0.25W, 1/4W Through Hole Resistor Axial | 1 | 2
R3 R4 | 311-47.0KFRCT-ND | RES SMD 47K OHM 1% 1/4W 1206 | 2 | 4
R2 R17 R18 | RMCF1206FT1M00CT-ND | RES SMD 1M OHM 1% 1/4W 1206 | 3 | 6
R5 R6 | S680KCACT-ND | RES 680K OHM 1/4W 1% AXIAL | 2 | 4
R1 R20 | 311-4.70KFRCT-ND | RES SMD 4.7K OHM 1% 1/4W 1206 | 2 | 4
R46 R47 | S22CACT-ND | RES 22 OHM 1/4W 1% AXIAL | 2 | 4
R40 | 311-13.0KFRCT-ND | RES SMD 13K OHM 1% 1/4W 1206 | 1 | 4
R33 R35 | S270KCACT-ND | RES 270K OHM 1/4W 1% AXIAL | 2 | 4
C5 | 399-5870-ND | CAP FILM 1UF 20% 630VDC RADIAL | 2 | 1
C5 | 1572-1018-ND | CAP FILM 1UF 10% 310VAC RADIAL | 1 | 2

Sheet: TopB V2
TopB V2
1000pF | 2 | C9 C15 | SMD0805
0.1uF | 1 | C19 | decouple 0805
0.1uF | 1 | C17 | decouple 0805
100nF | 4 | C1 C10 C11 | SMD0805
100nF |  | C3 | through hole | have via china
100nF 250V | 1 | C13 | SMD2420
0.47uF 275VAC | 2 | C4 C5
10uF 25V | 1 | C2
10uF | 1 | C16 | decouple 0805
10 uF tant | 1 | C6 | SMD1206
 | 1 | C8 | SMD1206
tant | 1 | C12
 | 1 | C14
 |  | C7 | SMD2312
 |  | C18 | SMD2917
1N5408 | 3 | D1 D2 D4
1N4004 | 5 | D3 D6 D7 D8 D9
SF35 | 1 | D5
LED3 | 1 | D10
LED2 | 1 | D11
INDUCTOR | 1 | L1
CONN_1 | 13 | P1 P2 P20 P21 P22 P23 P24 P26 P27 P28 P29 P30 P31
CONN_10X2 | 1 | P8
CONN_3 | 1 | P7
0 | 2 | R8 R19
300 | 1 | R11
330 | 2 | R22 R23
500 | 1 | R13
1K 0.25W | 1 | R4
1K | 1 | R15
4.53k | 1 | R7 | Take out
4K7 0.25W | 1 | R2
5k | 2 | R25 R26 | SMD1206
10K | 2 | R18 | SMD0805
10K | 2 | R20 | SMD0805
10k | 4 | R10 R12 R14 R21 | SMD1206
10k | 2 | R27 R28 | SMD0805
100K | 1 | R9 | SMD0805
1M 0.25W | 2 | R5 R6
1M5 | 1 | R17 | SMD2512
330 0.25W | 1 | R1
51ohm 0.25W | 1 | R3
RSENSE 0.05ohm | 1 | R16 | SMD2512
BT151 | 1 | SCR1
IRF644 | 1 | T1
NTC | 1 | TH1
4N25 | 1 | U1
OMEGA_PCC-SMP_K-TYPE | 1 | U2
MAX1771 | 1 | U3
MAX31855 | 1 | U4
LT3081 | 1 | U5
MAX6816 | 1 | U7
MAX9926/9927 | 1 | U6
HV SEL | 1 | U8
74LVC245 | 1 | U10
5K | 1 | VR1

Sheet: MAC10v2
0.1 uF | 12 | C3 C8 C10 C11 C14 C15 C17 C19 C21 C23 C26 C31 | decouple caps 0805
10 uF | 9 | C1 C2 C4 C6 C7 C9 C13 C16 C18 | SMD1206 | http://www.ebay.com/itm/100-PCS-A-1uF-35V-1206-3216-SMD-Tantalum-Capacitor-/321448011348
10uF | 2 | C20 C22 | SMD2312 | changed package from 1812 to 2312
22 uF | 1 | C5
15 pF | 2 | C12 C35 | use instock ones from RS
LED1 | 1 | D1
POWER | 1 | D2
LED | 3 | D3 Dx1 Dx2
LED3 | 1 | D5
LED2 | 1 | D6
LED0 | 1 | D7
RUN | 1 | D9
PROG | 1 | D10
FPGA PINS | 1 | P1
CONN_10X2 | 2 | P2 P8
PIC_ISP | 1 | P5
XILINX CABLE | 1 | P20
USB_Header | 1 | P3
DC IN | 1 | P15 | take out
^^NPN-BC817-SOT323 | 1 | Q5
^^NPN-SOT23 | 3 | Q1 Q2 Q3
0 | 8 | R5 R20 R7000 R7001 R7002 R7003 R7004 R7005 | use 0ohm ones in stock from china
100 | 3 | R21 R22 R23
300 | 2 | R2 R24 | get from china | http://www.ebay.com/itm/200pcs-300-ohm-300R-1-0805-2012-1-8W-SMD-Chip-Resistor-2mm-1-2mm-/331716171044
330 | 12 | R7 R8 R11 R15 R18 R19 R25 R26 R29 R41 Rx1 Rx2 | get from china | http://www.ebay.com/itm/5000PCS-0805-Chip-Resistors-330-ohm-330R-1-SMD-Resistors-1-8W-Chip-Resistor-/251924323249
470 | 5 | R12 R13 R16 R17 R32 | use 100ohm ones in stock from china
500 | 2 | R3 R31
1K | 4 | R14 R33 R35 R36
4.53k | 2 | R1 R9
4K7 | 4 | R6 R28 R30 R43
10k | 2 | R10 R27
10K | 2 | R39 R40
24.3K | 1 | R4
66.5K | 1 | R34
PROG_B | 1 | SW2
FLASH/RUN | 1 | SW4
SOFT_RESET | 1 | SW5
LT3081 | 2 | U1 U4
MT48LC64M4A2 | 1 | U2 | Have instock from Ebay
M25P80 | 2 | U6 U7
CH341A | 1 | U11
XC6SLX9-TQ144 | 1 | U30
XCF02S | 1 | U32
FPGA_CLK_0 | 1 | U33
PIC18F2520-28QFN | 1 | U3 | Have instock from Ebay
^^74LV244 | 1 | U5 | Have instock from RS
FT232R | 1 | Ux2
^^3.3VREG_SOT223 | 1 | Ux1 | Have instock from Ebay LM1117 3.3
12MHz | 1 | X2

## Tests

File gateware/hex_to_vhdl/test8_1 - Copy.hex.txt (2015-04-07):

:10 0000 00 000074FFF5801112007400F580111200 D9
:0E 0010 00 80EE1115227EFA7FFADEFEDFFC22 62
:00 0000 01 FF

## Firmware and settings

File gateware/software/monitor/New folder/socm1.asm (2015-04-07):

; 2013-10-20: A simple but working ROM monitor program for the great Z80 system-on-FPGA project - from Will Sowerbutts.
; 05-04-2015 Attempt at porting the monitor (from Sowerbutts) to to compiled on tasm z80 compiler 




; hardware register addresses
UART0_STATUS:  .EQU    $00 ; [7: RX READY] [6: TX BUSY] [6 unused bits]
UART0_DATA:    .EQU    $01
UART1_STATUS:  .EQU    $28
UART1_DATA:    .EQU    $29
STACK_INIT:    .EQU    $F000 ; stack (grows downwards, runtime movable)
INPUT_BUFFER:  .EQU    $EF00 ; input buffer (grows upwards, runtime movable)

SPI_CHIPSELECT: .EQU    $18
SPI_STATUS:     .EQU    $19
SPI_TX:         .EQU    $1a
SPI_RX:         .EQU    $1b
SPI_DIVISOR:    .EQU    $1c
GPIO_INPUT:     .EQU    $20
GPIO_OUTPUT:    .EQU    $21

MMU_SELECT:    .EQU    $F8   ; page table entry selector
MMU_PAGE17:    .EQU    $FA   ; magic I/O port that accesses physical memory
MMU_PERM:      .EQU    $FB   ; permission bits [6 unused bits] [WRITE] [READ]
MMU_FRAMEHI:   .EQU    $FC   ; high byte of frame number
MMU_FRAMELO:   .EQU    $FD   ; low byte of frame number
MMU_PTR_VAL0:  .EQU    $FC
MMU_PTR_VAL1:  .EQU    $FD
MMU_PTR_VAL2:  .EQU    $FE
MMU_PTR_VAL3:  .EQU    $FF

FLASH_MAN:     .EQU    $c2
FLASH_DEV1:    .EQU    $20
FLASH_DEV2:    .EQU    $17

RAM_MB: .EQU    $8

        ; on reset, the MMU maps us at $0000 for 4K,
        ; however it's really useful to have access to this
        ; first page because it's where we can put programs
        ; for CP/M to run, etc. So we remap ourselves up to
        ; $f000 and run from there.

.ORG $0000 ; early ROM location (also Z80 reset vector)

        ; test if we're cold booting -- have to do this reasonably quickly,
        ; before the SDRAM controller has initialised itself (~0.1msec)
        in a, (GPIO_INPUT)
        ld b, a ; stash that for now

        di ; disable interrupts (for those arriving via RST 0 rather than CPU reset)
        ; map page at $F000 to $2000000 physical (4K SRAM ROM)
        ld a, $f
        out (MMU_SELECT), a
        ld a, $20
        out (MMU_FRAMEHI), a
        xor a
        out (MMU_FRAMELO), a
        ld a, $03
        out (MMU_PERM), a
        ; jump to monitor in new location
        jp boot

.org $F000 + $
boot:
        ; use MMU to map SDRAM into page 0
        xor a
        out (MMU_SELECT), a
        out (MMU_FRAMEHI), a
        out (MMU_FRAMELO), a
        ld a, $03 ; map it read/write
        out (MMU_PERM), a

        ld a, b ; recover the coldboot flag
        and $80 ; had the SDRAM controller initialisation completed?
        jr z, warmboot ; yes! it's a warm boot then.

        ; no; it's a cold boot
        ld sp, $1000

        ld hl, coldbootmsg
        call outstring

        ; we're going to zero out RAM, each 4K page in turn
        ld hl, $0

        ; use frame starting at $1000
        ld a, 1
        out (MMU_SELECT), a
        ld a, $03
        out (MMU_PERM), a

        ; for each page ...
cbnextpage:
        ; map it in
        ld a, h
        out (MMU_FRAMEHI), a
        out (GPIO_OUTPUT), a ; also display code on LEDs
        ld a, l
        out (MMU_FRAMELO), a
        push hl ; stash page number

        ; write zeroes to the 4K page mapped at $1000....$1fff
        ld hl, $1000
        ld de, $1001
        ld bc, $0fff
        ld (hl), 0 ; fill memory with with 0s
        ldir

        pop hl ; recover page number (we overwrite it in cycle 0, but with 0s)
        inc hl
        ld a, l
        cp 0
        jr nz, cbnextpage
        ld a, h
        call outnibble       ; print char after each MB zeroed
        ld a, h
        cp RAM_MB ; test if we're up to system RAM size?
        jr nz, cbnextpage

        call outnewline

        ; turn off LEDs
        xor a
        out (GPIO_OUTPUT), a

        ; restore MMU config
        xor a
        out (MMU_FRAMEHI), a
        inc a
        out (MMU_FRAMELO), a

        ; fall through to warm boot process
warmboot:
        ld sp, STACK_INIT   ; load stack pointer to point to 1 byte past top of memory
        ld iy, INPUT_BUFFER ; set default input buffer location 256 bytes below top of stack

        ; put a reset vector in place to jump back into us
        ld a, $c3 ; jmp instruction
        ld (0), a
        ld hl, boot
        ld (1), hl

        ; turn off bright LEDs!
        xor a
        out (GPIO_OUTPUT), a

        ; print our greeting
        ld hl, greeting
        call outstring

        ; flush UART FIFO
fifoflush:
        in a, (UART0_DATA)     ; read byte from UART
        in a, (UART0_STATUS)   ; check status
        bit 7, a               ; test if data waiting
        jr nz, fifoflush       ; keep flushing if there is

monitor_loop:
        ld hl, monitor_prompt
        call outstring

        push iy ; HL=IY
        pop hl
        call instring
        call outnewline

        ld ix, cmd_table
testnextcmd:
        push iy ; HL=IY
        pop hl
        ; test for end of string
        ld a, (hl)
        cp 0
        jr z, monitor_loop
        ; load string address
        ld e, (ix+0)
        ld d, (ix+1)
        call cmdcompare
        jp z, runcmd
        ; advance ix to point to next command
        ld bc, 4
        add ix, bc
        ; list is terminated with a zero, check for that
        ld a, (ix+0)
        or (ix+1)
        cp 0
        jr nz, testnextcmd
        ; end of list but no command found
        ld hl, what_msg
        call outstring
        jr monitor_loop
runcmd: ; run command at ix+2, ix+3
        ld e, (ix+2)
        ld d, (ix+3)
        push de
        pop ix
        jp (ix)

do_help:
        ld hl, help_msg
        call outstring
        jp monitor_loop

; parse command line to display I/O register contents. call with (HL) pointing into input buffer after "in "
do_in:
        call skipspaces
        call parsehexorfail
        ; DE now contains the I/O address to read
        push de
        call outde
        ld a, $3d
        call outchar
        ld a, $20
        call outchar
        pop bc
        in a, (c) ; asserts full 16-bit address bus
        call outcharhex
        call outnewline
        call skipspaces
        ld a, (hl)
        cp 0
        jp z, monitor_loop  ; don't use ret, we get here by a jump and not a call.
        jr do_in  ; next address

; write to I/O register
do_out:
        call skipspaces
        call parsehexorfail
        ; DE now contains the I/O address
        push de
nextio:
        call skipspaces
        call parsehexorfail
        ; DE now contains the value to write
        ld a, d ; check D=0
        cp 0
        jr nz, invalid
        pop bc ; I/O address
        out (c), e
        inc bc ; next I/O address
        call skipspaces
        ld a, (hl)
        cp 0
        jp z, monitor_loop
        push bc
        jr nextio
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

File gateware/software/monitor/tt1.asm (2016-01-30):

;	10-Apr-2015		timer test v1 
;
;

; hardware register addresses
gpport:    .equ $21
gpport1:   .equ $39

UART0_STATUS:  .equ $00 ; [7: RX READY] [6: TX BUSY] [6 unused bits]
UART0_DATA:    .equ $01

END:	.EQU	$FF	; Mark END OF TEXT

reg1:	.equ $C000


    .ORG $B000

;init

    ; select upcounter latch value
    ld a, $11
    out ($11), a

    ld hl, alive1
    call outstring

    ld hl, reg1
    ld (hl), $F0

 ;	LD	A, $F0
 ;   out (reg1), a

start:

;	LD	A, $FF
;    out (gpport1), a

;	call StartTimer
;	call timerMH

; 	LD	A, $F0



	call StartTimer


start2:

	call timerMH
 ;   out (reg1), a
	LD B, A

	CP	$01					; test compare A to 0x01
	JP	Z, yes1				; is equal JUMP to
  	JP	start2				; is not equal
yes1:
	call togglePort1
	call StartTimer

	call PrintTimer

	jp start2






togglePort1:

;	in a, (reg1)
;    ld hl, reg1
;    ld a, (hl)

	LD IX,$C000				;load HL with 0xC000
	LD A, (IX + 0)


;	XOR A

	CP	$01					; test compare A to 0x01
	JP	Z, yes2				; is equal JUMP to
	LD A, $01
  	JP	ok2				; is not equal
yes2:
	LD A, $00
ok2:

 ;   out (reg1), a
;	ld hl, reg1
 ;   ld (hl), A

 	LD (IX + 0), A

    out (gpport1), a


	call outcharhex
	call outnewline

	ret



timerMH:
	call LatchTimer
    in a, ($16)
	CP	$01					; test for timer MidHigh =0x07
	JP	Z, timeriseq2		; JUMP IF equal to above
  	LD	A, $00				; loads 0x00 to Acc and returns -> not equal to compare value
	ret
timeriseq2:
    in a, ($15)
	CP	$86					; test for timer MidHigh =0x07
	JP	Z, timeriseq		; JUMP IF equal to above
  	LD	A, $00				; loads 0x00 to Acc and returns -> not equal to compare value


	ret
timeriseq:
  	LD	A, $01				; loads 0x01 to Acc and returns -> is equal to compare value
	ret



PrintTimer:
	;print the latched timer value.
    ld hl, timerdone
    call outstring
    in a, ($17)
    call outcharhex
    in a, ($16)
    call outcharhex
    in a, ($15)
    call outcharhex
    in a, ($14)
    call outcharhex
    call outnewline
	ret





StartTimer:
   ; reset hardware timer
    ld a, $01
    out ($11), a
	ret

LatchTimer:
; latch hardware timer value
    ld a, $02
    out ($11), a
	ret




;--------------------------------------------------------------------------------------------  uart routines  (down) -----------------


; outstring: Print the string at (HL) until 0 byte is found
; destroys: AF HL
outstring:
        ld a, (hl)     ; load next character
   ;     and a          ; test if zero


	CP	END			; TEST FOR END BYTE
	JP	Z,outstringEND		; JUMP IF END BYTE IS FOUND


   ;     ret z          ; return when we find a 0 byte
        call outchar
        inc hl         ; next char please
        jr outstring
outstringEND:
		ret

; print the byte in A as a two-character hex value
outcharhex:
        push bc
        ld c, a  ; copy value
        ; print the top nibble
        rra
        rra
        rra
        rra
        call outnibble
        ; print the bottom nibble
        ld a, c
        call outnibble
        pop bc
        ret

; print the nibble in the low four bits of A
outnibble:
        and $0f ; mask off low four bits
        cp 10
        jr c, numeral ; less than 10?
        add a, $07 ; start at 'A' (10+7+0x30=0x41='A')
numeral:
		add a, $30 ; start at '0' (0x30='0')
        call outchar
        ret

; outchar: Wait for UART TX idle, then print the char in A
; destroys: AF
outchar:
        push bc
        ld b, a
        ; wait for transmitter to be idle
ocloop: in a, (UART0_STATUS)
        bit 6, a
        jr nz, ocloop   ; loop while busy

        ; now output the char to serial port
        ld a, b
        out (UART0_DATA), a
        pop bc
        ret

; output a newline
outnewline:
        ld a, $0d   ; output newline
        call outchar
        ld a, $0a
        call outchar
        ret

;--------------------------------------------------------------------------------------------  uart routines  (up) -----------------



DELAY2:
	LD	C,$91	;d1
	LD	B,$E1	;d2
	LD	A,$23	;d3
again31:
	DEC	C
	JP	Z, again30
	JP again31
again30:
	DEC	B
	JP	Z, again32
	JP again31
again32:
	DEC	A
	JP	Z, again33
	JP again31
again33:
	RET


alive1:
	.BYTE "Alive tt1",END
timerdone:
	.BYTE "Timer 0x",END


	.END

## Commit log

2015-04-07 gateware: socZ80 brought up on the MAC-10 Spartan-6 board
    Imported from original project folder:
    backup 07-04-2015 2139
    218 files changed, 187518 insertions(+)
    Based on socZ80 2014-04-30 release (git 33e313f7) by
    William R Sowerbutts <will@sowerbutts.com>, GPLv3.
2015-10-12 logic-board: S6LX9 R2 schematic and layout
    backup 12-10-2015 2033
    6 files changed, 18011 insertions(+)
    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
    [S6LX9_R2.brd, S6LX9_R2.sch]
2015-10-12 logic-board: S6LX9 R2 layout routing
    backup 12-10-2015 2130
    1 file changed, 321 insertions(+), 124 deletions(-)
    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
    [S6LX9_R2.brd]
2015-10-12 logic-board: S6LX9 R2 layout routing
    backup 12-10-2015 2333
    6 files changed, 2479 insertions(+), 2082 deletions(-)
    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
    [S6LX9_R2.brd, S6LX9_R2.sch]
2015-10-17 cdi-board: TopV1 - first top board
    FPGA_TopV1
    16 files changed, 39099 insertions(+)
    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
    [TopV1-B_Mask.gbs, TopV1-B_SilkS.gbo, TopV1-Bottom.gbl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]
2016-01-30 gateware: AntsMod 3
    05-04-2015 AntsMod 3
    56 files changed, 94434 insertions(+), 25598 deletions(-)
    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
2016-02-11 logic-board: S6LX9 R2 schematic and layout updates
    19-02-2016 1257
    6 files changed, 7256 insertions(+), 2460 deletions(-)
    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
    [S6LX9_R2.brd, S6LX9_R2.sch]
2016-02-18 cdi-board: MAC-10.0 Test Board
    FPGA_TopVtester
    31 files changed, 48282 insertions(+), 29014 deletions(-)
    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
    [TopV1.brd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]
2016-02-21 logic-board: S6LX9 R2 first gerbers
    21-02-2016 2246
    14 files changed, 67271 insertions(+), 6747 deletions(-)
    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
    [S6LX9_R2-B_Mask.gbs, S6LX9_R2-B_SilkS.gbo, S6LX9_R2-Bottom.gbl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]
2016-02-27 gateware: AntsMod 4 - ignition timer work
    27-02-2016 2313
    17 files changed, 14141 insertions(+), 13239 deletions(-)
    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
2016-02-28 gateware: AntsMod 4 - ignition timer work
    28-02-2016 2056
    11 files changed, 12256 insertions(+), 12131 deletions(-)
    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
2016-02-29 gateware: AntsMod 4 - ignition timer work
    29-02-2016 1850
    8 files changed, 13210 insertions(+), 13135 deletions(-)
    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
2016-03-01 gateware: AntsMod 4 - ignition timer work
    01-03-2016 1900
    9 files changed, 12554 insertions(+), 12511 deletions(-)
    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
2016-03-03 gateware: AntsMod 4 - ignition timer work
    03-03-2016 1913
    11 files changed, 13364 insertions(+), 13324 deletions(-)
    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
2016-11-04 cdi-board: TopB 2E (silkscreen REV 2.0) - MAX1771 boost + SCR CDI
    FPGA_TopVtester2E
    38 files changed, 139397 insertions(+), 57689 deletions(-)
    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
    [BOM.xlsx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]
2016-12-19 gateware: AntsMod 4 - MAC10v2 board pinout
    19-12-2016 2212
    2 files changed, 8 insertions(+), 3 deletions(-)
    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
2017-01-02 logic-board: MAC10 REV 2.0 - final gerbers, BOM and schematic
    FPGA_S6LX9_R2
    18 files changed, 438793 insertions(+), 30159 deletions(-)
    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
    [BOM 28-12-2016.xlsx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]
2017-01-07 gateware: AntsMod 4 - interrupt controller, monitor ROM
    07-01-2017 1719
    10 files changed, 21397 insertions(+), 25 deletions(-)
    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
2017-01-08 gateware: AntsMod 4 - final
    31-01-2016 AntsMod 4
    17 files changed, 34757 insertions(+), 12925 deletions(-)
    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
2017-01-15 cdi-board: TopB 3 (silkscreen REV 3.0)
    FPGA_TopVtester3
    22 files changed, 34061 insertions(+), 134143 deletions(-)
    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
    [BOM.xlsx, TopVVtester2E.brd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]
2017-01-15 gateware: AntsMod 5 - final MAC10v2 build
    08-01-2017 AntsMod 5
    11 files changed, 12451 insertions(+), 12444 deletions(-)
    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
2017-01-16 cdi-board: TopB 2 (silkscreen REV 1.0) - BOM
    FPGA_TopVtester2
    29 files changed, 613294 insertions(+), 23130 deletions(-)
    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
    [BOM.xlsx, BOM2.xlsx, BOM2_1.xlsx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]
2017-01-23 cdi-board: TopB 2 - reduced CDI experiment
    FPGA_TopVtester2 - Copy
    2 files changed, 72 insertions(+), 768 deletions(-)
    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
    [TopVVtester2.sch]
2017-03-19 cdi-board: TopB 4 - TL494 push-pull HV converter redesign
    FPGA_TopVtester4
    42 files changed, 33249 insertions(+), 628597 deletions(-)
    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
    [BOM.xlsx, BOM2.xlsx, BOM2_1.xlsx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]
2026-10-09 Add README, licensing and board renders
    Gateware, software and tools: GPL-3.0-or-later (required by socZ80).
    Hardware: CERN-OHL-S-2.0. Docs and images: CC-BY-4.0.
    Replace the "All Rights Reserved" notice in hex_to_vhdl and the
    MonZ80.vhd/obj_code_pkg.vhdl it generates with a GPL-3.0-or-later notice.
    Board images are rendered from the fabrication gerbers (gerbv) and the
    board files (KiCad 10).
